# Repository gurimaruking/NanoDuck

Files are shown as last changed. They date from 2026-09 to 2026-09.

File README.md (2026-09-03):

# NanoDuck — MG90S で成立する小型二足アヒル

[MicroDuck](https://github.com/pollen-robotics/microduck)（250 mm / 800 g /
Dynamixel XL330 ×14 / 約 63,000 円のサーボ）を、**ホビーサーボで作り直した**もの。

MicroDuck を縮小コピーしたのではない。一度そう試して**幾何的に成立しないことを確認した**
（§3）ので、MG90S の形と能力に合わせて引き直してある。

数値はカタログ値の掛け算ではなく、**実機出荷版の歩行ポリシー `alpha_walking.onnx` を
CPU MuJoCo で 30 秒走らせて実測した関節トルク・角速度**
（`analysis/microduck_demand.npz`、5348 サンプル × 14 関節）から導いている。

```
analysis/  design_point.py      設計点の決定（質量 × 脚長 × サーボ割当）
           servo_sizing.py      初期検討（相似縮小の限界。経緯として残す）
cad/       build_nanoduck.py    MJCF を生成し、静的バランスを検証
           check_servo_fit.py   実装密度の検証 ← 部品を買う前にこれ
sim/       nanoduck.xml         生成されたモデル（10 DOF, 241 g、実メッシュ入り）
           stand_test.py        MG90S で立てるか
           run_mg90s.py         MicroDuck を MG90S で走らせる（アクチュエータ検証）
bom/       bom.csv              部品表
```

```bash
python cad/build_nanoduck.py   # モデル生成 + バランス検証
python sim/stand_test.py       # 立つか
```

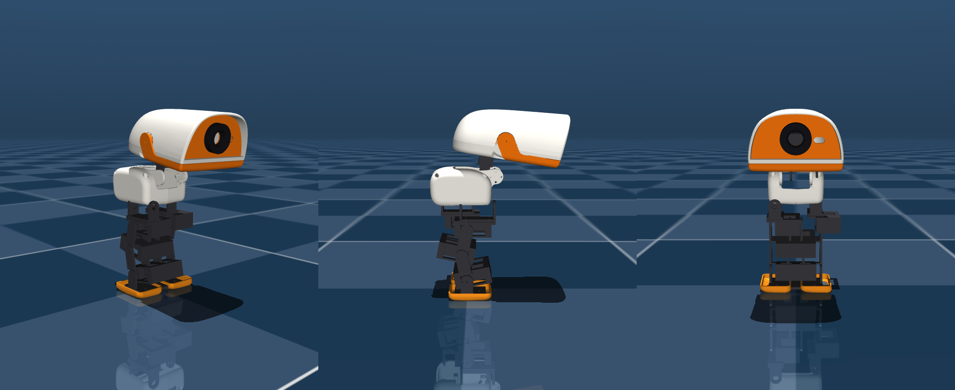
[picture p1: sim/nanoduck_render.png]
NanoDuck


上は箱ではなく**実物のジオメトリ**です。白いシェル(頭・胴・水かき足)は
MicroDuck 本体のメッシュを縮小したもの、黒い脚は `cad/print/` の印刷部品そのもの。
質量と慣性を担う箱はグループ3に隠してあり、`geomgroup` を切り替えれば質量モデルが見えます。

---

## 1. 設計点

| | MicroDuck | **NanoDuck v2** |
|---|---|---|
| 全高 | 250 mm | **177 mm** (71 %) |
| 質量 | 800 g (MJCF 737 g) | **284 g** (36 %) |
| 全長 × 全幅 | — | 130 × 83 mm |
| DOF | 14 | **10** |
| サーボ | XL330 ×14 @7.4 V | MG92B ×2（膝）+ MG90S ×7 + マイクロ ×1 @6.0 V |
| 制御 | RK3566 / Linux | ESP32-S3-MINI-1 |
| サーボ費用 | 約 63,000 円 | **約 7,300 円** (1/9) |
| 脚長（腿+脛） | 91.6 mm | 50 mm |
| 最悪関節の使用率 | 76 %（膝） | **90 %**（膝） |

質量と寸法は見積りではなく `sim/nanoduck.xml` の実測。**モデルが正**。

MicroDuck 自身が「限界設計だが成立している」76 % に座っているので、そこを上限に
設計した。いまは **90 %** で、上限を超えている。

**「見た目クリソツ」の代償が積み上がった結果**:

| 段階 | 質量 | 最悪関節 |
|---|---|---|
| 構造だけ（見積り） | 196 g | 62 % |
| 印刷部品の実測 + 外装 | 241 g | 76 % |
| **頭を本家比率（0.85）に** | **284 g** | **90 %** |

頭を本家と同じ head/body = 1.52 にすると +43 g かかる。0.62 のままなら比 1.11 で
27 % 小さく、「アヒルだが何か違う」という見え方になっていた（§8）。
90 % は `design_point.py` の転写が MicroDuck の**機敏な歩容**を前提にした上界なので、
再学習した歩容ならもっと軽い。ただし余裕が無いのは事実で、
**軽くしたいならまず頭のスケールを下げる**のが一番効く。

高さが 71 % にしか下がらないのは、**サーボと電池が縮まないから**（§2）。
一方で質量は 27 %、サーボ費用は 11 % まで落ちる。
「小さくする」より「軽くする・安くする」プロジェクトだと理解した方が正しい。

---

## 2. 設計変数は「相似縮尺 s」ではなく「質量」と「脚長」

最初は MicroDuck を s 倍する枠組みで考えたが、これは**間違った定式化**だった。
一つの s が全部に掛かるため、関節が実際に気にしている 2 つの量が独立に動かせない。

関節需要の転写則:

```
τ = τ_micro · (M/M_micro) · (L_leg/L_micro)     (τ ~ M·g·L)
ω = ω_micro · √(L_micro/L_leg)                  (振子周期 ~ √(L/g))
P ~ τ·ω ~ M · √L_leg
```

**質量は 1 乗、脚長は 1/2 乗でしか効かない。**
脚を半分にして得られるのは出力予算の 29 %、質量を半分にすれば 50 %。
だから設計努力は mm ではなく **g** に注ぐ。

MG90S の脚が運べる質量（最悪関節 ≤ 100 %）:

| 脚長 | 全部 MG90S | 膝だけ MG92B |
|---|---|---|
| **50 mm** | 220 g | **315 g** ← 採用 |
| 70 mm | 205 g | 245 g |
| 100 mm | 170 g | 180 g |

脚を 70 → 50 mm に詰めたのは、造形の都合が先だった（70 mm では竹馬に乗った
ロボットに見えて、アヒルに見えなかった）。結果としてトルク予算も 245 → 315 g に
増えて、**見た目の判断と工学の判断が同じ方を向いた**。
代償は歩幅と地上高で、屋内 177 mm のロボットなら払える。

**膝 2 個を格上げする方が、機体をどう削るより効く。**
+0.8 g・+1,100 円で予算が 40 g 増える。ここに金を使う。

### 質量には床(floor)がある

サーボ・電池・基板は縮まない。s³ で縮むのは構造材だけ。
NanoDuck では **196 g のうち構造材は 33 g（17 %）**しかなく、残りは全部固定質量。
「もっと小さくすれば軽くなる」は、この規模ではもう成り立たない。

> 初期の見積りでは電池と基板を s³ 項に入れていた。450 mAh の LiPo は縮まないので、
> これは小スケールを不当に有利に見せる誤りだった。CAD メッシュの実測
> （`np_f970.stl` は名前に反し **NP-F550 寸法と 0.2 mm 一致** = 約 76 g）で
> 3 項モデルに組み直してある。

---

## 3. 縮小コピーが成立しなかった理由 — MG90S は「小さい」のではなく「薄い」

| | 長さ | 高さ | 幅 | 質量 |
|---|---|---|---|---|
| XL330-M288 | 34.0 mm | 29.0 mm | 20.0 mm | 18.0 g |
| MG90S（耳込み） | 32.2 mm | 28.5 mm | 12.2 mm | 13.4 g |
| 比 | **0.95** | **0.98** | 0.61 | 0.74 |

よく言われる「MG90S は XL330 の 45 % の体積」は事実だが**完全にミスリード**。
連鎖方向の長さが制約なので、効くのは長さで、そこは **5 % しか縮んでいない**。

MicroDuck の股関節は 3 DOF を 71 mm に詰めている = サーボ 1 個あたり 23.7 mm、
XL330 は 34 mm なので**既に 43 % 重なっている**。0.56 倍にすると、
実証済みの実装密度の **1.7 倍**が要る。トルクではなく実装が律速だった。

### 解決 — サーボを横に倒す

MG90S の出力軸は 22.8×12.2 面から出る。ピッチ関節では軸が左右方向を向くので、
**32.2 と 12.2 を矢状面内で自由に選べる**。12.2 を脚に沿わせれば:

| | 連鎖長/サーボ |
|---|---|
| サーボを連鎖に沿わせる（MicroDuck 流） | 40.2 mm |
| **サーボを横に倒す** | **20.2 mm** |

NanoDuck は腿 25 mm / 脛 25 mm なので実装密度 **0.81**（MicroDuck は 1.44）。
ブロッカーは取付向きだけで消えた。代償は腿が前後に 32 mm 張り出すこと —
アヒルなら「もも肉」に見えるので、制約とキャラクタが珍しく一致している。

詳細: [cad/README.md](cad/README.md) / `python cad/check_servo_fit.py`

---

## 4. MG90S アクチュエータモデル — 実装済み・検証済み

`sim/mg90s.py`。`sim/run_mg90s.py` が microduck_rl の `infer_policy.py` を
そのまま駆動し、**アクチュエータだけ**を差し替える。

```bash
cd sim
python run_mg90s.py --servo xl330      # 対照群
python run_mg90s.py --servo mg90s-6v   # 本命
python run_mg90s.py --servo mg90s-6v --view
```

MuJoCo の `position` アクチュエータを**トルクモードに変換**し、毎物理ステップで計算:

```
err  = deadband(q_target − q)          # ポテンショは出力軸を読む
u    = clip(kp·err / τ_stall, −1, +1)  # アナログP制御 → PWMデューティ
τ    = τ_stall·u − (τ_stall/ω_noload)·q̇
```

第 2 項の逆起電力が**トルク-速度の三角形**を作る。`position` の平坦な `forcerange`
では「速く回すほどトルクが出ない」を表現できず、ベンチでは崩れるロボットが
シム内では平然と歩いてしまう。

### 対照群による較正（これが無いと信用できない）

最初の実装は「誤差 1° でフルドライブ」= 実効剛性 55 Nm/rad とし、MJCF の
`chosen_actuator` が定める **kp = 0.55 Nm/rad の 100 倍**だった。
結果、**XL330 の数値でも 2.4 秒で転倒**。対照群が歩かないならモデルが悪い。

副産物として良い整合が出た: MJCF の `damping = 0.053` は逆起電力項を持たない
position モデル用の値なので逆起電力を吸収しているはず。実際
0.053 − (0.963/20.2) = **0.0054** で、BAM が独立にフィットした
`friction_viscous = 0.00536` と **1 % 以内で一致**する。

### 結果（MicroDuck 実寸・出荷版歩行ポリシー・15 s）

| サーボ | 結果 |
|---|---|
| XL330 @7.4 V（対照群） | **歩く** 2.65 m / 14.3 s、飽和 0 % |
| MG90S @6.0 V | **1.1 s で転倒**、飽和 64 % |

### アブレーション — 犯人は「関節剛性ひとつ」

MG90S は XL330 と**出力**と**制御則**の 2 点で違う。片方ずつ入れ替えると
実寸では**どちらも単独で致命的**（出力だけ → 1.7 s、制御則だけ → 1.9 s で転倒）。

制御則をさらに 3 要素に分解:

| 変更（XL330 の出力のまま） | 結果 |
|---|---|
| 不感帯 1.0° | **歩く**（飽和 0 %） |
| 指令遅延 20 ms（50 Hz PWM 1 フレーム） | **歩く** |
| kp 0.8 / 1.0 / 1.2 Nm/rad | **歩く** |
| kp 1.5 Nm/rad | 5.1 s で転倒 |
| **kp 2.47 Nm/rad**（MG90S 相当） | **0.8 s で転倒** |

**ハード設計への含意:**
- **333 Hz PWM は不要** — 標準 50 Hz の 20 ms 遅延は問題にならない
- **不感帯 1° も許容** — 姿勢精度は落ちるが安定性は壊さない
- **効くのは関節剛性ひとつ** — MG90S は自身のトルクに対し XL330 の約 4.5 倍硬い

ただしこれは**未再学習のポリシー**の話。RL は硬いアクチュエータを扱えるので、
kp ≈ 2.5 をドメインランダム化に含めて学習し直せば解ける見込みが高い。
結論は「MG90S は無理」ではなく**「再学習は必須で、そのとき剛性が最重要パラメータ」**。

---

## 5. 立てるか — 立てる（が、それは簡単な方の問題）

`python sim/stand_test.py`。ポリシー無しで STAND 姿勢を保持させ、重力をかける。

| サーボ | 結果 |
|---|---|
| XL330（対照群） | 立つ。たわみ 0.2 mm、rms 0.00 mm、飽和 0 % |
| **設計どおり（MG92B 膝 + MG90S + マイクロ）** | **立つ。たわみ 0.2 mm、飽和 0 %** |
| 全部 MG90S | 立つ。同上 |

不感帯 1° があってもリミットサイクルは出ず、静止する。

**ただしこれは簡単な方の問題**で、静的保持では 3 構成に差が出ない。
横から押すと 0.15 m/s でも全構成が転ぶが、そのとき**サーボは一度も飽和していない** —
つまりトルク不足ではなく**バランス制御が無いから**倒れている。
固定姿勢の保持に外乱復帰はできない。それはポリシーの仕事で、
`stand_test.py` はこの 2 つの失敗モードを区別して報告する。

**設計を本当に検証するのは、10 DOF で再学習した歩行ポリシー**。
`analysis/design_point.py` が心配しているのは遊脚期の出力であって、静止時の保持ではない。

### 最初のモデルは後ろに倒れた

ホームポーズに MicroDuck の関節角（腿 −26.2°、膝 ≈0、足首 +26.2°）を
数値のまま流用したのが原因。あれは**脚全体が前傾した**姿勢で、MicroDuck では
3 サーボの股関節クラスタが足を前に送り出して釣り合う。
単純な 2 軸股関節に入れると足が CoM より 31 mm 前に出て、後ろ向きに座り込む。

2 リンク脚で足首を股関節の真下に置く条件は **knee = −2·hip_pitch**、
足裏を水平にするのは **ankle = −(hip_pitch + knee)**。
いまはこれを式で導出しており、`build_nanoduck.py` が生成のたびに
**CoM が支持多角形に入っているか**を検証する（現在: 前後余裕 +16.2 mm、左右 +33.0 mm）。

---

## 6. 位置フィードバックが要る

観測 49 次元の内訳:

```
base_ang_vel(3) + gravity(3) + joint_pos(10) + joint_vel(10) + last_action(10) = 36
                                                            + command(13)      = 49
```

**関節エンコーダ由来が観測 36 次元中 20 次元**。MG90S は PWM 位置指令のみで出力を返さないので、
内部 5 kΩ ポテンショのワイパーを引き出す（[bom/README.md](bom/README.md) §4 に
落とし穴 3 つ: 分圧必須・低抵抗厳禁・コンデンサ容量）。

---

## 7. 残っている作業

1. **MG90S / MG92B のベンチ実測** — `sim/mg90s.py` の `kp`・不感帯・ストールトルクは
   推定値。シムの結論は kp に最も敏感なので、ここが最優先。
   MG92B のカタログ値はベンダー間でばらつきが大きく、設計はこれに依存している
2. **再学習** — `Mjlab-Velocity-Flat-NanoDuck` を登録し、MG90S アクチュエータモデルと
   kp のドメインランダム化を入れて PPO。観測 49 / 行動 10 の新しい契約になる
3. **機構設計** — サーボ横倒しレイアウトで実際に CAD を引く。
   `sim/nanoduck.xml` は箱を並べた運動学モデルであって、製造できる形状ではない。
   Onshape の MicroDuck は公開されている（[cad/README.md](cad/README.md)）が、
   参照用であって派生元にはしない
4. **ESP32-S3 への載せ替え** — 49→128→128→10 なら 23k パラメータ = 92 KB で
   量子化なしに内蔵 SRAM に載る

---

## ライセンス

上流 microduck_rl と同じ 2 分割構成:

- **コード** (`analysis/`, `sim/*.py`, `cad/*.py`, ドキュメント) — [Apache 2.0](LICENSE)
- **3D モデル** (`cad/microduck_src/`) — **CC BY-NC-SA 4.0**。
  Pollen Robotics の [microduck_rl](https://github.com/pollen-robotics/microduck_rl)
  からのコピーで、**商用利用不可・継承必須**。派生物である
  `analysis/microduck_demand.npz` も同条件

詳細と、なぜこれらのファイルを同梱しているかは [NOTICE.md](NOTICE.md)。

本家は Pollen Robotics の [MicroDuck](https://pollen-robotics.com/microduck)。
NanoDuck は非公式の独立リデザインで、Pollen Robotics とは関係ありません。

---

## 8. 頭部まわりの監査（未解決を含む）

### 比率 — 直した

MicroDuck の head/body 比は **1.52**。頭 0.62 / 胴 0.85 と別スケールにしていたため
NanoDuck は **1.11** で、27 % 小さかった。これが「アヒルだが何か違う」の正体。
頭を胴と同じ 0.85 にして 1.52 を厳密に回復した（+43 g、膝 76 → 90 %）。

### head_yaw の駆動 — 足りていなかった

`design_point.py` は頭の関節需要も**脚長でスケール**していた。首サーボが支えるのは
脚ではなく頭なので、これは誤り。頭のスケールで転写し直すと:

| | 旧（脚スケール） | 新（頭スケール） |
|---|---|---|
| head_yaw 必要トルク | 0.038 Nm | **0.050 Nm** |
| マイクロ 3.7 g の使用率 | 83 % | **102 %（成立しない）** |

→ head_yaw を **MG90S に格上げ**（27 %）。neck_pitch はマイクロのままでよい（34 %）—
こちらは短いアームで重力に抗するだけで、頭の慣性を振り回さない。

### センサ — 穴はあるが中身が無い

| | MicroDuck | NanoDuck |
|---|---|---|
| サイト | imu, imu_bno, head_camera, mouth_tip, tof, head_imu | imu, head_camera, **tof**, **head_imu**, mouth_tip |
| 実カメラ | RPi カメラ + M12 レンズ | **無し（`ncam = 0`）** |
| ToF | 有り | **無し** |

サイトは MicroDuck と同じ名前で揃えた（歩行の観測は胴の IMU だけなので機能上は不要だが、
外装が MicroDuck 製で**穴が開いている**以上、位置はモデルに書いておくべき）。

**未解決**: 頭のシェルにはレンズ穴と ToF 窓があるのに、BOM には何も入っていない。
どちらかを選ぶ必要がある:
- **目隠しプラグを印刷する**（軽い。歩行には何も要らない）
- **OV2640 等を積む**（ESP32-S3 で駆動可。ただし §3 の「歩行だけ」という前提が変わる）

### 腰まわり — サーボは全部ある。フレームが無い

`cad/build_nanoduck.py` の `check_joints()` で確認済み:

- サーボ 10 個すべてモデルに存在（hip_roll ×2 と neck_pitch は胴に載っている）
- 軸の向き、ホームが範囲内、キーフレーム一致、ctrlrange 一致、左右の鏡像性、
  膝の符号（足首が股関節の真下 ±0.00 mm）— **全項目合格**

**未解決**: hip_roll サーボ 2 個を保持する**胴体シャーシがまだ描かれていない**。
質量 12 g で見積もってあるだけで、印刷部品が無い。
`cad/print/` に無い唯一の構造部品で、ここが腰まわりの本当の穴。

### 首まわり — 3 件とも実バグだった

「首まわりがおかしい」で見つかったもの:

1. **首の印刷部品が上下逆** — `parts.link()` は全部品を「駆動側が −Z」で作る。
   脚 6 部品はこれで正しいが、首だけは **+Z**（頭は上）。
   部品は z = −44〜+5 に伸びていて、**頭のある上ではなく胴の中へ向いていた**。
   親の部品が自分の駆動する関節位置に届いているかを検証する
   `check_joints()` の到達テストで検出（脚 6 部品は合格、首だけ不合格）。

2. **頭が胴に 10.6 mm めり込んでいた** — これが「首が見えない」の正体。
   首が無いのではなく、頭が胴の中にあった。`NECK_SINK = 8` と `HEAD_Z = 4` は
   37 mm の頭には妥当だったが、0.85 で 50 mm になった頭には過補正。
   いまは**閉形式で導出せず測って収束させている**（`solve_head_z()`）—
   閉形式は 2 回間違えた（neck_pitch の傾きで頭の底面が下がる分、
   クラスタの重心が最下点ではない分を、どちらも落としていた）。
   `check_head_clearance()` がコンパイル済みモデルから実測する。

3. **色が無かった** — シェルは別部品なので個別に着色できる。実物は
   オフホワイト + **オレンジのくちばしと眉帯** + 黒い目。
   単色クリームだと「白い汎用ロボット」に見えてしまう。

なお「頭が 40° 傾いて見える」は**目視の誤り**で、実測ピッチは **+8.6°**
（= `NECK_PITCH_0` そのまま）。見えていた傾きは MicroDuck 自身の楔形の頭蓋。

### 腰まわり — 軸が平行だった（`8d6f5fb` で修正済み）

hip_roll と hip_pitch は**直交**しなければならないが、平行になっていた。
いま股関節は 2 部品のコーナーリンク（`hip_yoke_a` + `hip_yoke_b`）で、
`check_joints()` が軸の向きを検証している。

**未解決のまま**: hip_roll サーボ 2 個を保持する胴体シャーシは依然として未描画。
`cad/print/` に無い唯一の構造部品。

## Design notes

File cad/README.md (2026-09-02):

# CAD

```
microduck_src/     MicroDuck の原寸メッシュ(上流のコピー、47 STL + MJCF)
nanoduck_s050/     0.50 倍に縮小したもの(scale_meshes.py の出力、参考用)
scale_meshes.py    一様スケール
check_servo_fit.py MG90S が入るかの検証  ← 先にこれを読む
```

## 出典とライセンス

`microduck_src/` は [pollen-robotics/microduck_rl](https://github.com/pollen-robotics/microduck_rl)
の `src/mjlab_microduck/robot/microduck/assets/` をそのままコピーしたもの。

> 3D model files are licensed under Creative Commons **BY-SA-NC**.
> (microduck_rl の LICENSE 記載)

したがって `nanoduck_s050/` などの派生物も **CC BY-SA-NC** を継承する。
**商用利用不可**、**継承(SA)必須**、**表示(BY)必須**。

CAD の本体は Onshape にあり公開されている:
https://cad.onshape.com/documents/804927696f06d877f3f1803e

本気で作るならこれを自分のドキュメントにコピーしてパラメトリックに変更し、
[onshape-to-robot](https://github.com/Rhoban/onshape-to-robot) で再エクスポートする。
`microduck_src/config_mjcf_walk.json` がそのエクスポート設定そのもの。

---

## 先に読むこと — MG90S は「入らない」

```bash
python check_servo_fit.py
```

**MG90S は小さいサーボではない。薄いサーボである。**

| | 長さ | 高さ | 幅 | 質量 |
|---|---|---|---|---|
| XL330-M288 | 34.0 mm | 29.0 mm | 20.0 mm | 18.0 g |
| MG90S(耳込み) | 32.2 mm | 28.5 mm | 12.2 mm | 13.4 g |
| 比 | **0.95** | **0.98** | 0.61 | 0.74 |

よく言われる「MG90S は XL330 の 45 % の体積」は事実だが**完全にミスリード**。
連鎖方向の長さが制約なので、効くのは体積ではなく長さで、そこは **5 % しか縮んでいない**。

### なぜ「リンク長 ≥ サーボ長」では判定できないか

MicroDuck の股関節は 3 DOF を 71 mm の連鎖に収めている = **サーボ1個あたり 23.7 mm**。
XL330 は 34 mm なので、既にサーボ同士が 43 % 重なっている。
多自由度クラスタでは「入るか」ではなく**実装密度**で見るしかない:

```
実装密度 = サーボ長 ÷ (連鎖長 ÷ サーボ数)
```

| クラスタ | 連鎖 | 数 | mm/個 | MicroDuck 実績 | NanoDuck s=0.56 で必要 |
|---|---|---|---|---|---|
| 股 (yaw+roll+pitch) | 71.0 mm | 3 | 23.7 | 1.44 | **2.43** |
| 頭 (pitch+yaw+roll) | 73.7 mm | 3 | 24.6 | 1.38 | **2.34** |
| 腿→膝 | 42.2 mm | 1 | 42.2 | 0.81 | 1.36 |
| 脛→足首 | 49.4 mm | 1 | 49.4 | 0.69 | 1.16 |

**s=0.56 では MicroDuck が実証済みの密度の 1.7 倍が要る。**
これは幾何の問題なので、再学習でもギヤでも動かない。

### 制約が交差している

```
幾何:   MicroDuck と同じ実装密度を守るなら s ≥ 0.95(237 mm)= ほぼ縮まない
トルク: MG90S @6.0V が成立するのは s ≤ 0.56(140 mm)
                            ↑ 重ならない
```

**ここが NanoDuck の本丸**。トルクではなく実装が律速。

### 抜け道(安い順)

1. **DOF を減らす** — 一番きつい頭部クラスタ(pitch+yaw+roll が 24.6 mm/個)は
   歩行に不要。`head_yaw` と `head_roll` を落として 14 → **12 DOF**。
   再学習はどのみち必須なので、14 アクション契約を守る理由はない
2. **サーボを混ぜる** — 首・頭は s=0.56 換算で 0.018–0.025 Nm しか要らない
   (膝は 0.12 Nm)。3.7 g マイクロサーボで十分で、場所が空く
3. **遠隔駆動** — 膝・足首のサーボを胴体に移してリンク機構で駆動する。
   200 mm 以下の二足では定石。脚の体積が丸ごと空く。代償はバックラッシだが、
   これは `add_backlash.py` で既にモデル化されている

v1 BOM は 1 + 2 を採用している([../bom/README.md](../bom/README.md))。
3 は股関節が 12 DOF でもまだ密なので、いずれ必要になる可能性が高い。

---

## scale_meshes.py

```bash
python scale_meshes.py --scale 0.50
```

バイナリ STL を一様スケールする。一様スケールでは面法線は不変(単位ベクトル)なので、
三角形あたり 9 個の頂点 float だけを触る。スケール比は検証済み(実測 0.500)。

**これは形状確認とシム用**であって完成した機械設計ではない。スケールしないものが3つある:

- **サーボ座**: 全部 XL330 (29×20×34) 用に彫られている。MG90S は出力軸が片側のみで
  耳が横に出る、まったく別のインタフェース。全部引き直し
- **肉厚**: 0.5 倍は 2 mm の壁を 1 mm にする。FDM で出しにくい上に荷重的に足りない。
  肉厚は「絶対値」で戻すもので、スケールするものではない
- **買う部品**: ベアリング・ネジ・電池は実寸のまま。M2 は M2 のまま、
  MicroDuck の 22×16×4 ベアリングは MR63/MR83 になるのであって
  11×8×2(存在しない)にはならない

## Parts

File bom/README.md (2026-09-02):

# NanoDuck v2 — BOM と電装の設計判断

**設計点: 10 DOF / 脚長 50 mm / 実装質量 196 g / 全高 162 mm**
最悪関節 **62 %**（MicroDuck 自身の膝は 76 %。それより余裕がある）

数値は `sim/nanoduck.xml` の実測。**モデルが質量の正**であって、見積りではない。

MicroDuck をスケールした設計ではない。MG90S の形に**合わせて**引き直したもの。
根拠は `analysis/design_point.py`、機構の判断は [../cad/README.md](../cad/README.md)。

---

## 1. なぜ 10 DOF か

| | MicroDuck | NanoDuck v2 |
|---|---|---|
| 脚 | hip_yaw, hip_roll, hip_pitch, knee, ankle ×2 = 10 | hip_roll, hip_pitch, knee, ankle ×2 = **8** |
| 首・頭 | neck_pitch, head_pitch, head_yaw, head_roll = 4 | neck_pitch, head_yaw = **2** |
| 合計 | 14 | **10** |

- **hip_yaw を落とす**: 4 DOF 脚は歩行の古典的最小構成。旋回は左右非対称な歩幅で作れる
- **head_pitch / head_roll を落とす**: 頭部 3 DOF クラスタはロボット上で最も密（連鎖 24.6 mm/個）で、
  歩行には何も寄与しない
- **首と頭ヨーは残す**: 頭が動かないアヒルは家具

再学習は必須（[../README.md](../README.md) §4）なので、14 アクションの観測契約を守る理由はない。

## 2. サーボ — 膝だけ格上げする

関節ごとの必要トルクは**桁で違う**。全部同じサーボにするのは設計ではなく手抜き:

| 関節 | サーボ | 必要トルク | 使用率 |
|---|---|---|---|
| knee ×2 | **MG92B** | 0.071 Nm | **62 %** ← 律速 |
| head_yaw | マイクロ 3.7 g | 0.027 Nm | 59 % |
| hip_pitch ×2 | MG90S | 0.044 Nm | 35 % |
| ankle ×2 | MG90S | 0.032 Nm | 18 % |
| neck_pitch | マイクロ 3.7 g | 0.011 Nm | 18 % |
| hip_roll ×2 | MG90S | 0.025 Nm | 13 % |

**膝 2 個を MG92B にすると、積める質量の上限が 220 g → 315 g に増える（脚長 50 mm）。**
フットプリントは MG90S と同一（22.8×12.2）、+0.4 g、追加費用 1,100 円。
機体を 40 g 削る努力より圧倒的に安い。**ここに金を使う。**

> MG92B のスペックはベンダー間で数値がばらつく。ここでは保守側（0.31 Nm @6V）を
> 採ったが、**ベンチ実測するまで信用しないこと**。MG90S も互換品の個体差が大きいので、
> 同一ロットでまとめ買いする。

## 3. 制御 — ESP32-S3-MINI-1、開発ボードではなくモジュール

MicroDuck の出荷ポリシー実測: 入力 61 → 出力 14、約 193k パラメータ、775 KB (float32)。
NanoDuck は 10 DOF なので観測 49 次元・行動 10 次元に縮み、さらに軽くなる:

```
base_ang_vel(3) + gravity(3) + joint_pos(10) + joint_vel(10) + last_action(10) = 36
                                                            + command(13)      = 49
```

| | 値 | 判定 |
|---|---|---|
| 演算量 | 193k MAC × 50 Hz = 9.7 MMAC/s | S3 には軽い |
| float32 の重み | 775 KB | 内蔵SRAM 512 KB に**入らない** |
| **int8 量子化後** | **193 KB** | **内蔵SRAM に載る** |
| PSRAM から float32 | 38.8 MB/s | 帯域が際どい |

**判断: PSRAM 無しの N8 モジュール + ESP-DL int8 量子化。**
どのみち再学習するので MLP を 61→128→128→14（26k パラメータ = 104 KB）に
縮めれば量子化すら不要になる（10 DOF なら 49→128→128→10 で 23k = 92 KB）。
PSRAM 付きを買う理由がない。

**開発ボードではなくモジュールを使う理由**: DevKitC は 8 g あり、その大半は
USB コネクタとピンヘッダ。196 g の機体で 8 g は膝の使用率 2 ポイントに相当する。

基板は 40×30 mm の 2 層 1 枚に ESP32-S3-MINI / PCA9685 / MCP3208×2 / 6V BEC /
IMU / 分圧抵抗 20 本を載せる。ブレイクアウト 5 枚をやめると約 15 g と配線の大半が消える。

> MicroDuck の RK3566 はカメラ・WebRTC・ToF・Linux を回している。
> ESP32-S3 は**歩行に必要な部分だけ**。映像が要るなら別の設計になる。

## 4. サーボ位置フィードバック（ポテンショ・タップ）

MG90S / MG92B に位置出力は無いが、観測 36 次元中 20 次元が関節角度・角速度なので必須。
内部 5 kΩ ポテンショのワイパーを引き出す。**落とし穴が 3 つある**:

1. **電圧** — ワイパーはサーボ電源（6 V）基準。ADC の 3.3 V を超えるので**必ず分圧**する
2. **負荷** — そのポテンショはサーボ自身の制御ループが使っている。低抵抗で分圧すると
   **サーボが目標位置をずらす**。100 kΩ / 100 kΩ 以上にすること
   （5 kΩ 源に 200 kΩ 負荷 → 誤差 2.5 %、許容範囲）
3. **帯域** — 100 k/100 k の出力インピーダンスは 50 kΩ。MCP3208 は 10 kΩ 以下想定なので
   **10 nF** を足す（時定数 0.5 ms、50 Hz 制御に間に合う）。
   1 µF を付けると 50 ms になって制御が破綻する

**ADC**: 10 ch を 50 Hz 以上で読む。ADS1115 は **860 SPS しか出ないので不可**。
MCP3208（12 bit / 8 ch / SPI / 100 kSPS）× 2 が素直。

## 5. 電源 — 電池容量は「稼働時間」ではなく「関節トルク」の判断

MG90S ストール電流は約 700 mA。8 個で最悪 5.6 A。
歩行中の平均は 150–200 mA/個 = **1.2–1.6 A**。

- **6 V BEC は 6 A 以上**。基板に載せるならスイッチング型で
- サーボ電源とロジック電源は**必ず分ける**。突入で ESP32 がリセットする
- サーボレールに 470 µF 低ESR を基板上で 2 本

| 電池 | 質量 | 稼働 | 最悪関節 |
|---|---|---|---|
| 2S 300 mAh | 17 g | 約 12 分 | 59 % |
| **2S 450 mAh** | **28 g** | **約 19 分** | **62 %** ← 採用 |
| 2S 850 mAh | 48 g | 約 35 分 | 69 % |

脚を 70 mm から 50 mm に詰めたことで予算に余裕ができ、電池はもう律速ではなくなった。
450 mAh は 19 分・使用率 62 % で、850 mAh に増やしても 69 % なのでまだ成立する。
重量が効く設計であることは変わらないので、まず 450 mAh で始める。

---

## BOM

[bom.csv](bom.csv)。購入合計 **約 28,700 円**（予備込み）。
うちサーボは約 7,300 円 — XL330 ×14 の約 63,000 円に対して **1/9**。

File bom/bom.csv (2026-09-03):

category | item | spec | qty | unit_price_jpy | subtotal_jpy | mass_g_each | on_robot_g | notes
servo | MG92B | metal gear / ~3.1kgf-cm @6V / 13.8g | 3 | 900 | 2700 | 13.8 | 27.6 | KNEES ONLY (2 + 1 spare). Same 22.8x12.2 footprint as MG90S, +0.4g, ~45% more torque. Moves the mass budget from 205g to 245g -- cheaper than any airframe diet. PROVISIONAL SPEC: bench-measure before trusting.
servo | MG90S | metal gear / 2.2kgf-cm @6V / 13.4g | 9 | 350 | 3150 | 13.4 | 93.8 | 7 used (hip roll x2, hip pitch x2, ankle x2, HEAD YAW) + 2 spare. head_yaw was a 3.7g micro until the head grew to MicroDuck proportions: 54g of shell at 0.85 scale puts a micro servo at 102% of its envelope. Buy one lot; clones vary.
servo | micro servo 3.7g | ~0.06Nm / 20x8.4x20mm | 2 | 600 | 1200 | 3.7 | 3.7 | 1 used (neck_pitch) + 1 spare. neck_pitch works against gravity on a short arm (34%); head_yaw works against the head's inertia and needed an MG90S.
compute | ESP32-S3-MINI-1-N8 | 8MB flash / no PSRAM | 2 | 900 | 1800 | 1.0 | 1.0 | Module, not a devkit: a devkit is 8g of USB connector and headers we do not need. No PSRAM because the policy is quantised to int8 (193KB) and lives in internal SRAM.
compute | custom control PCB | 40x30mm 2-layer | 1 | 3000 | 3000 | 11.0 | 11.0 | Carries the ESP32-S3-MINI, PCA9685, MCP3208, 6V BEC, IMU and the 10 pot dividers. One board instead of five breakouts saves ~15g and most of the wiring.
driver | PCA9685 | 16ch 12-bit PWM I2C (bare IC) | 2 | 300 | 600 | 0.2 | 0.2 | 10 servos; ESP32-S3 LEDC has only 8 channels.
sensing | MCP3208 | 12-bit 8ch SPI ADC 100kSPS | 2 | 400 | 800 | 0.3 | 0.3 | 10 pot-tap channels needs 2. ADS1115 at 860 SPS is far too slow -- do not substitute.
sensing | ICM-42688-P | 6-axis IMU SPI (bare IC) | 2 | 1500 | 3000 | 0.1 | 0.1 | Only gyro(3) + accel(3) are in the observation. MPU-6050 works for v1 if cost matters.
power | LiPo 2S 450mAh LiHV | 7.4V 30C ~28g | 2 | 1600 | 3200 | 28.0 | 28.0 | ~19 min walking at ~1.5A. 850mAh is +20g and costs 4 points of joint margin -- see README 5.
power | switching BEC 6V 6A |  | 1 | 1200 | 1200 | 10.0 | 0.0 | Only if not integrating the BEC on the PCB. 5A is NOT enough: 8 servos stalling is ~5.6A.
power | XT30 connector pair |  | 2 | 150 | 300 | 2.0 | 2.0
power | electrolytic 470uF 16V | low ESR | 2 | 60 | 120 | 1.5 | 3.0 | Across the servo rail, at the board.
sensing | resistor 100k 1% | 0603 | 30 | 3 | 90 | 0.01 | 0.3 | Pot dividers, 2 per channel. NOT lower: loading the 5k pot shifts the servo.
sensing | capacitor 10nF | 0603 | 15 | 3 | 45 | 0.01 | 0.15 | ADC anti-alias. NOT 1uF: 50ms time constant would break 50Hz control.
wiring | silicone wire 26AWG | servo power | 2 | 400 | 800 |  | 5.0
wiring | ribbon + JST-SH assortment | signal | 1 | 800 | 800 |  | 3.0
mech | bearing MR63ZZ | 3x6x2.5mm | 12 | 120 | 1440 | 0.4 | 4.0 | MG90S output shaft is single-sided; every joint needs an idler bearing opposite the horn.
mech | carbon rod 3mm | for the shin | 1 | 500 | 500 |  | 2.0
mech | M2 screw assortment | 6/8/10mm + nuts | 1 | 1200 | 1200 |  | 6.0
mech | PETG filament | 1kg | 1 | 2500 | 2500 |  | 33.0 | ~33g printed: trunk shell 10, 8 joint brackets 12, feet 7, head/neck 4. Building the geometry turned up brackets the first round-number estimate missed. PETG over PLA: the joints see real load.
 |  |  |  | PURCHASE TOTAL | 29445 |  |  | Includes spares. Servo cost ~7050 JPY vs ~63000 for 14 XL330.
 |  |  |  | ON-ROBOT MASS |  |  | 283.7 | Matches sim/nanoduck.xml exactly -- the model is the authority on mass. Worst joint: knee at 90%. It was 62% before the shells and 76% before the head was brought to MicroDuck proportions; looking right costs 87g and 28 points of margin.

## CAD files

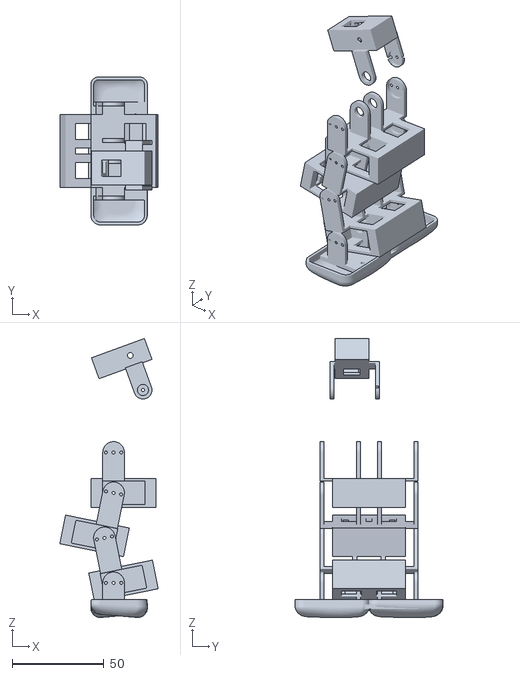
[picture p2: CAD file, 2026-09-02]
cad/print/assembly.stl
53.6 x 80.5 x 151.9

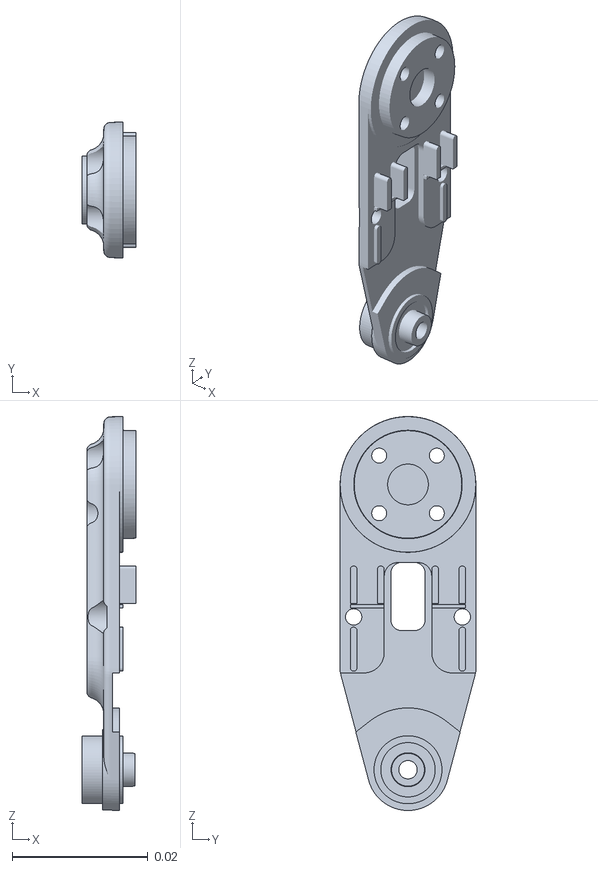
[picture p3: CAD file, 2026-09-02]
cad/microduck_src/leg.stl
0.00795 x 0.02 x 0.058

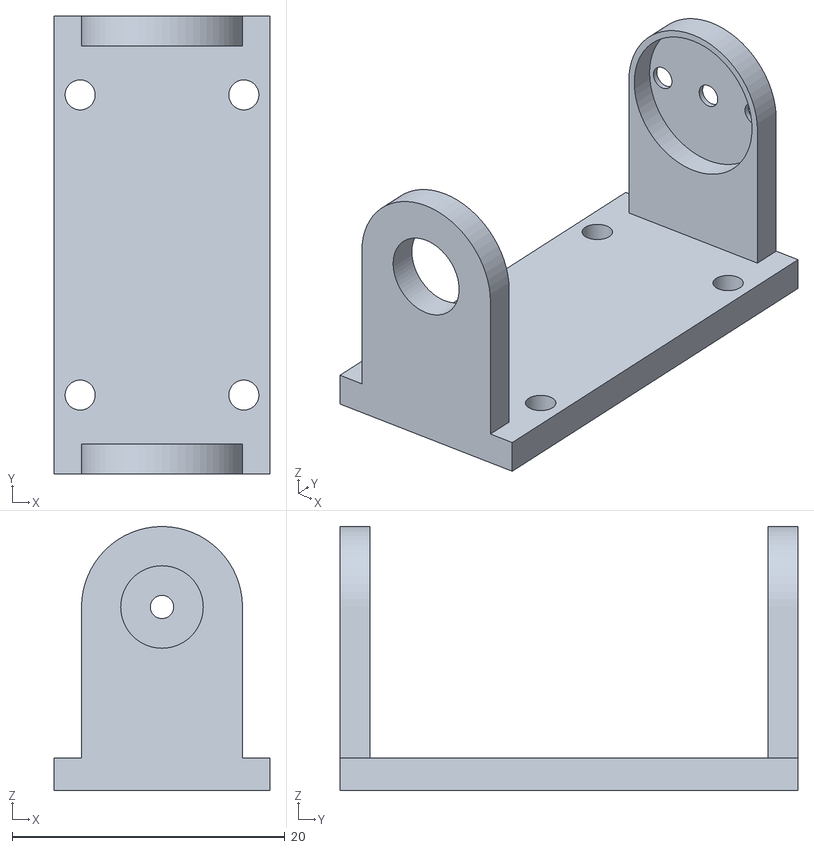
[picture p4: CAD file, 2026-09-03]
cad/print/hip_yoke_a_L.stl
15.8 x 33.6 x 19.3

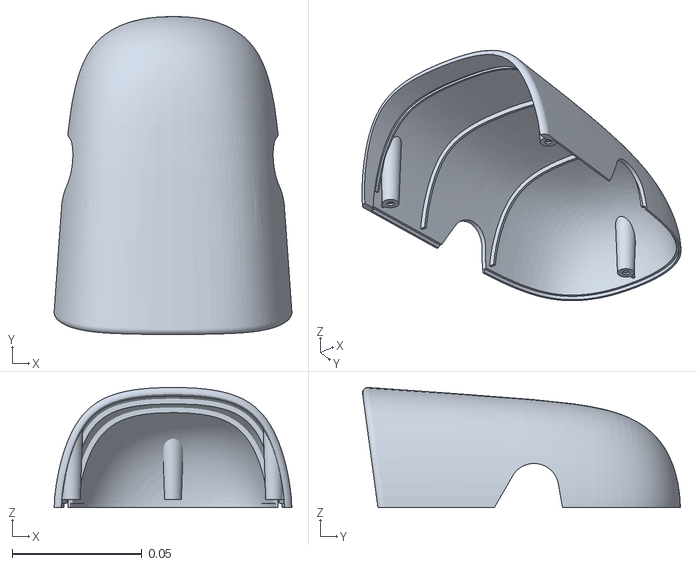
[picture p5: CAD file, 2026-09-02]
cad/microduck_src/top_head_shell.stl
0.0918 x 0.123 x 0.0463

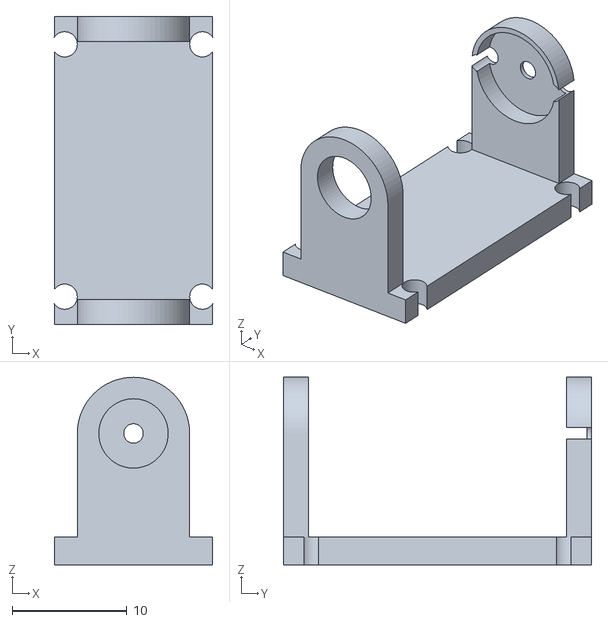
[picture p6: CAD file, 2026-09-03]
cad/print/neck_link_a.stl
13.8 x 26.8 x 16.3

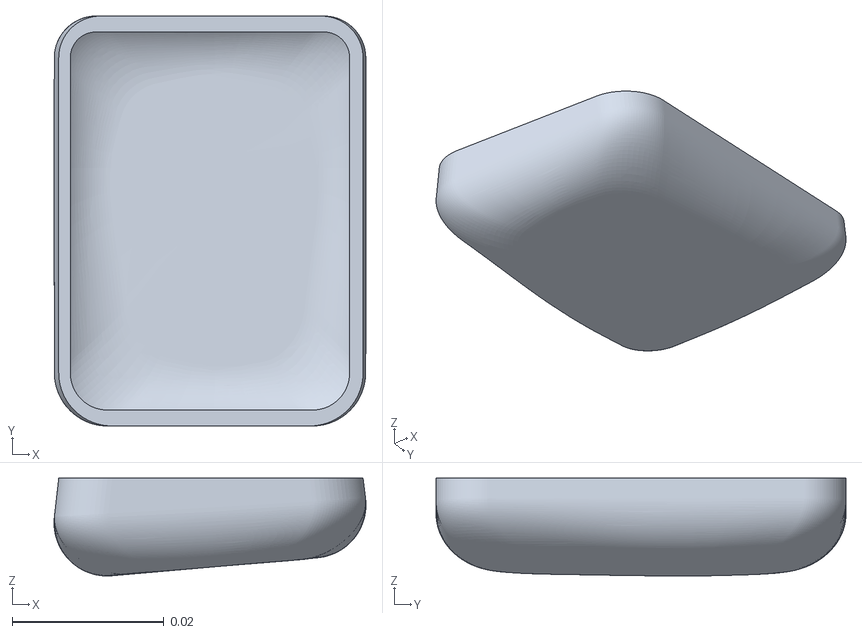
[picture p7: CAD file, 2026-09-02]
cad/microduck_src/sole_left.stl
0.0411 x 0.054 x 0.0129

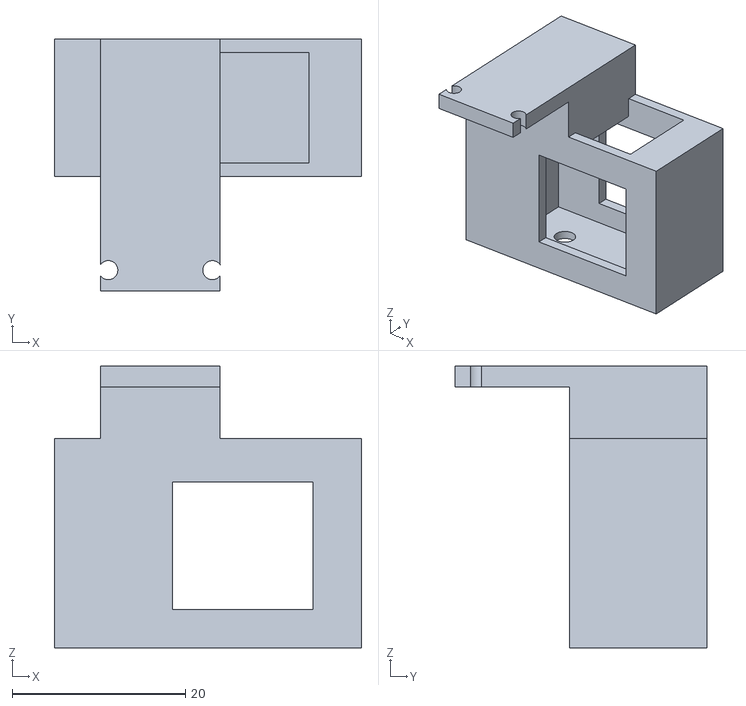
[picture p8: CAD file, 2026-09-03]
cad/print/neck_link_b.stl
35.4 x 29.1 x 32.5

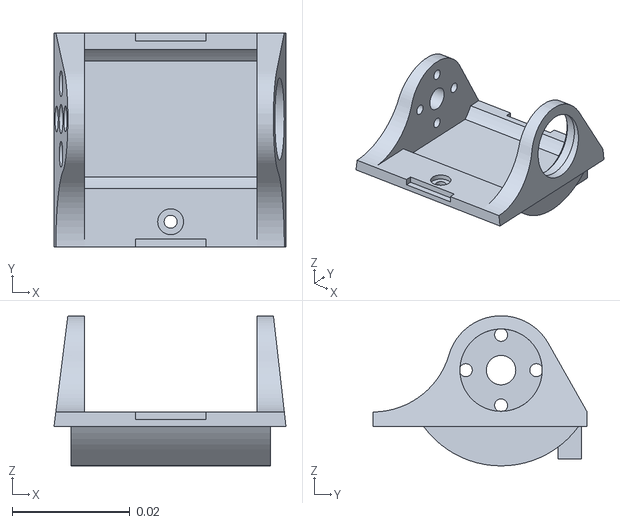
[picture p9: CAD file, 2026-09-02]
cad/microduck_src/ankle_right.stl
0.0395 x 0.0365 x 0.0255

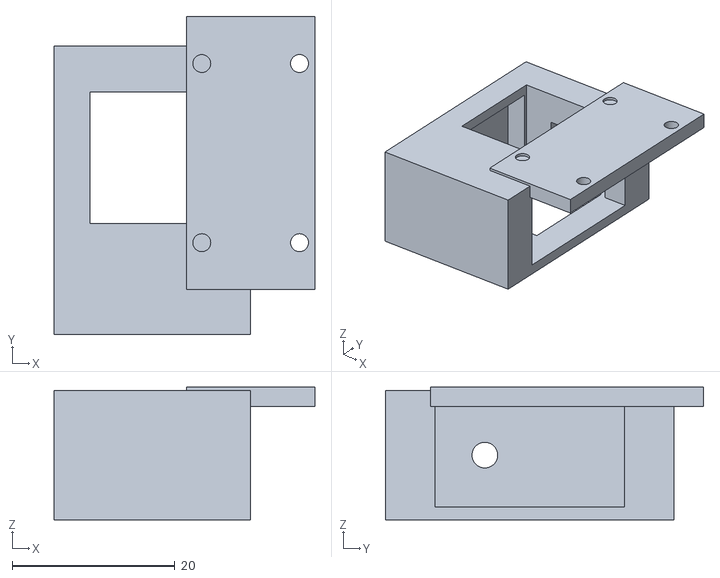
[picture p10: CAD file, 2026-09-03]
cad/print/hip_yoke_b_R.stl
32.0 x 39.1 x 16.3

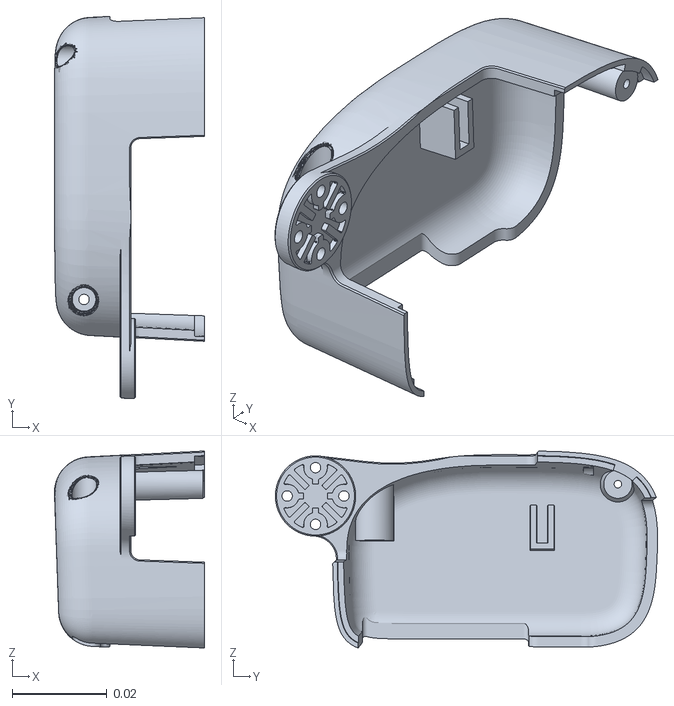
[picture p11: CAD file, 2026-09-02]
cad/microduck_src/right_shell.stl
0.0318 x 0.0809 x 0.0417

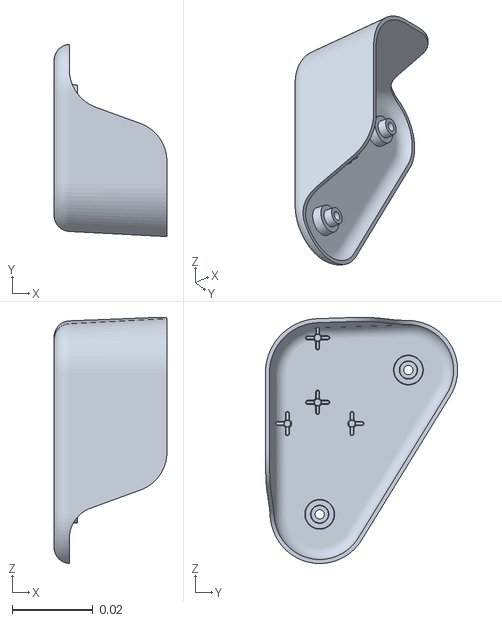
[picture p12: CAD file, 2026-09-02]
cad/microduck_src/right_upper_leg.stl
0.028 x 0.0477 x 0.061

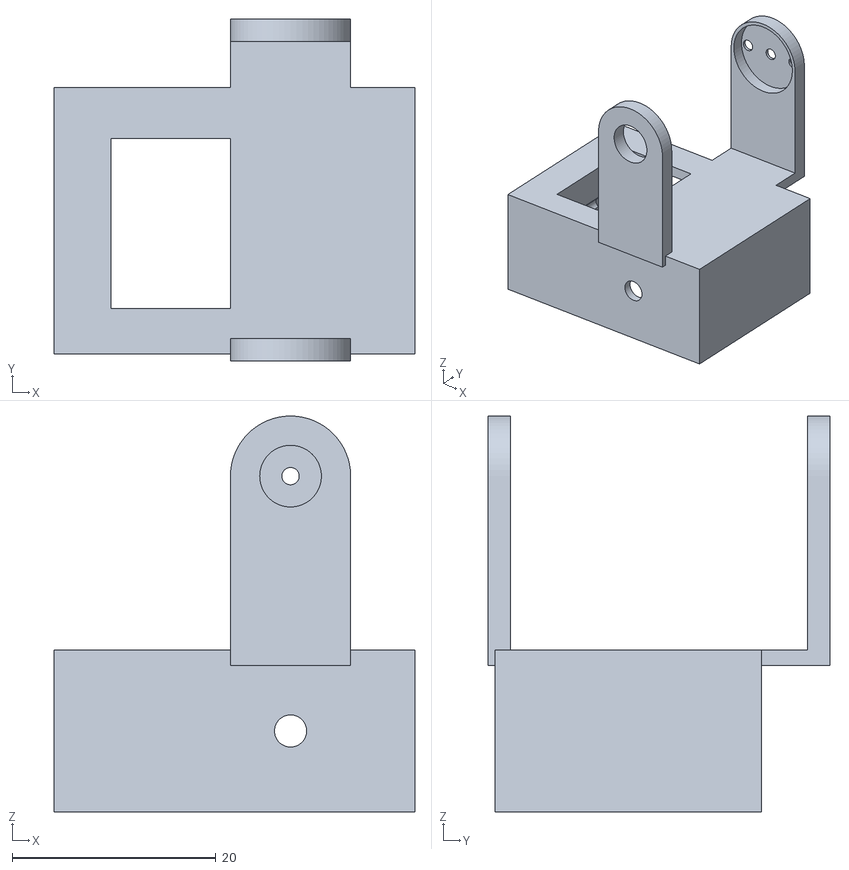
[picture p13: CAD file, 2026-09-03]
cad/print/thigh_L.stl
35.4 x 33.6 x 38.9

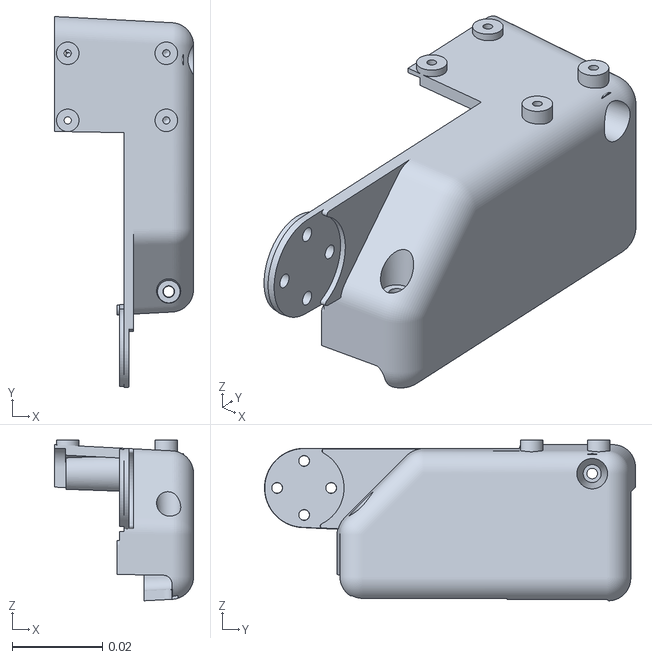
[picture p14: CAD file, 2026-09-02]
cad/microduck_src/trunk_shell_left.stl
0.0309 x 0.0824 x 0.0357

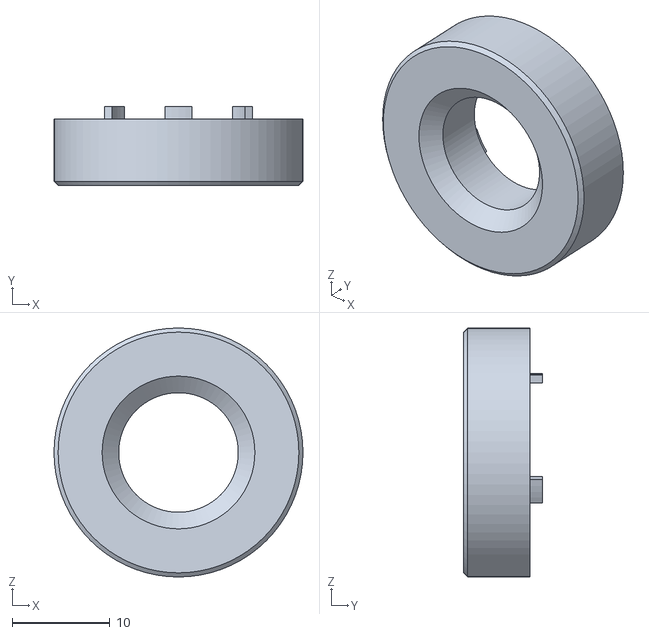
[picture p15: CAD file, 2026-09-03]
cad/print/cosmetic_noenoeil.stl
25.5 x 8.08 x 25.5

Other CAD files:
cad/print/hip_yoke_a_R.stl
cad/microduck_src/sole_right.stl
cad/print/hip_yoke_b_L.stl
cad/microduck_src/neck.stl
cad/microduck_src/ankle_l_v1.stl
cad/microduck_src/ankle_left.stl
cad/microduck_src/ankle_r_v1.stl
cad/microduck_src/banana_pcb_locker.stl
cad/microduck_src/bearing_roll.stl
cad/microduck_src/bottom_head_shell.stl
cad/microduck_src/elec_rpi_robot_hat_pcb.stl
cad/microduck_src/face_part.stl
cad/microduck_src/foot_left.stl
cad/microduck_src/foot_right.stl
cad/microduck_src/hip_l.stl
cad/microduck_src/jaw.stl
cad/microduck_src/jaw_soft.stl
cad/microduck_src/left_shell.stl
cad/microduck_src/left_upper_leg.stl
cad/microduck_src/lens.stl
cad/microduck_src/m12_lens_holder.stl
cad/microduck_src/motor_support.stl
cad/microduck_src/neck_pitch.stl
cad/microduck_src/noenoeil.stl
cad/microduck_src/np_f970.stl
cad/microduck_src/pcb__raspberry_pi_zero_2_w.stl
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

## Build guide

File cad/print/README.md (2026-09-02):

# NanoDuck 印刷部品

`python ../parts.py` で生成。20 STL、印刷質量 **64 g**(予備・治具を除く)。

> **最初に `fit_coupon_carrier` と `fit_coupon_yoke` だけ印刷してください。**
> 10 分で刷れて、サーボ・ベアリング・M2 ネジの嵌合を全部確認できます。
> ここで合わなければ、それは `../servo_spec.py` の数値が手持ちのサーボと違うという意味で、
> **16 個の構造部品すべてが同じように間違っています。**

---

## 1. 部品表

### 構造(パラメトリック生成)

| 部品 | 個数 | 印刷質量 | 外形 | 中身 |
|---|---|---|---|---|
| `hip_yoke_L/R` | 2 | 2.89 g | 35×34×36 | hip_roll に跨り、hip_pitch サーボを保持 |
| `thigh_L/R` | 2 | 3.14 g | 35×34×39 | hip_pitch に跨り、膝サーボ(MG92B)を保持 |
| `shin_L/R` | 2 | 2.97 g | 35×36×39 | 膝に跨り、足首サーボを保持 |
| `foot_mount_L/R` | 2 | 1.37 g | 30×34×20 | 足首に跨り、足裏を留める |
| `neck_link` | 1 | 1.67 g | 31×27×31 | neck_pitch に跨り、head_yaw サーボを保持 |
| `fit_coupon_carrier` | 治具 | 3.96 g | 44×27×26 | 嵌合テスト |
| `fit_coupon_yoke` | 治具 | 0.86 g | 12×34×23 | 嵌合テスト |

### 外装(MicroDuck 実物メッシュの縮小)

| 部品 | 縮尺 | 印刷質量 | 外形 |
|---|---|---|---|
| `cosmetic_top_head_shell` | 0.62 | 8.14 g | 57×76×29 |
| `cosmetic_bottom_head_shell` | 0.62 | 6.48 g | 57×72×12 |
| `cosmetic_jaw` | 0.62 | 2.55 g | 57×43×18 |
| `cosmetic_face_part` | 0.62 | 1.59 g | 54×8×28 |
| `cosmetic_noenoeil`(目、2個) | 0.62 | 1.16 g | 19×6×19 |
| `cosmetic_left_shell` / `right_shell` | 0.85 | 7.99 / 7.87 g | 29×69×35 |
| `cosmetic_sole_left` / `right` | 0.75 | 3.01 g | 31×40×10 |

外装は**模倣ではなく本物**です。Pollen Robotics の
[microduck_rl](https://github.com/pollen-robotics/microduck_rl) のメッシュそのもの
(**CC BY-NC-SA**、[../../NOTICE.md](../../NOTICE.md))。頭と胴で縮尺が違うのは、
胴が縮まない電池と基板を飲み込む必要があるためです。

> **クリソツの代償**: 外装だけで 43 g あり、膝の使用率を 62 % → **76 %** に押し上げます。
> 62 % は MicroDuck より余裕がある状態、76 % は MicroDuck と同じ限界設計です。
> 見た目を取るか余裕を取るかは、この 43 g の判断です。

---

## 2. 印刷設定

| | |
|---|---|
| 材料 | **PETG**(PLA 不可 — 関節に実荷重がかかる) |
| ノズル / 層厚 | 0.4 mm / 0.2 mm |
| 外周 | **4**(壁 1.6 mm を前提に設計) |
| 上下面 | 4 層 |
| インフィル | 35 % gyroid |
| サポート | **不要**(サーボポケットは +Y に開口、全オーバーハングが造形面を向く) |
| 配置 | 構造部品は**キャリア底面を造形板に**。層が関節荷重と直交します |

PLA で刷る場合は `../servo_spec.py` の `CLEAR` を 0.25 → 0.15 に下げてください
(PETG の膨張を見込んだ値です)。

---

## 3. 組立

必要なハード(1 関節あたり):

- M2 タッピングねじ ×2(サーボの耳)
- M2 タッピングねじ ×3(ホーンをヨーク腕へ)
- MR63ZZ ベアリング ×1(3×6×2.5)
- 3 mm ピンまたは M3 ねじ、長さ 8 mm ×1

手順(1 関節):

1. サーボをキャリアに **+Y 側から落とし込む**。耳が座に密着すること
2. 耳を M2 タッピング ×2 で締める。締めすぎるとボスが割れます
3. MR63ZZ をヨークの **−Y 腕**に圧入
4. ホーンをヨークの **+Y 腕**の座に落とし、M2 タッピング ×3 で固定
5. ホーンをサーボのスプラインに嵌め、付属の中心ねじで留める
6. 3 mm ピンをキャリア底面の穴からベアリング内輪へ通す

**必ずサーボを中立位置に合わせてからホーンを嵌めてください。** ホーンは 18° 刻みでしか
噛まないので、ずれると可動域の非対称(下記)が逆側に出ます。

---

## 4. 可動域は「実測値」です

`parts.py --check` が各関節を掃引し、子のヨークが親のキャリアに当たる角度を
ブーリアン交差で測っています。レンダリングでは絶対に見えません。

| 関節 | 可動域 | ホーム位置 |
|---|---|---|
| hip_pitch | **−32.5° 〜 +100.0°** | +11.5° |
| knee | **−102.5° 〜 +32.5°** | −22.9° |
| ankle | **−10.0° 〜 +22.5°** | +11.5° |

非対称なのはサーボ本体が前後の片側に張り出しているためです。
**膝キャリアだけ X 反転**してあり、広い 100° 側が実際に膝が曲がる向きに来ています
(反転前はホーム −22.9° に対し限界 −25°、余裕 2° しかありませんでした)。

これらは `../build_nanoduck.py` の `JOINTS` にそのまま入っていて、
MJCF の関節リミットになります。**機構が回らない角度を学習させないため**です。

> ⚠️ **足首の 32° が現状いちばん厳しい制約**です。歩容を縛るはずなので、
> 機構側で次に直すならここです。

---

## 5. まだ無いもの

- **胴体シャーシ** — hip_roll サーボ ×2、首サーボ、電池、基板を保持する枠。
  質量 12 g で見積もってありますが、まだ描いていません
- **外装の位置合わせ** — `preview.py` は構造部品しか配置しません。
  MicroDuck のシェルは Onshape 由来の原点と軸を持っており、
  当てずっぽうで置いたら「それらしく見えて間違っている」結果になったので外しました
- **MG92B の実測** — カタログ値がベンダー間でばらつきます。設計はこの数値に乗っています

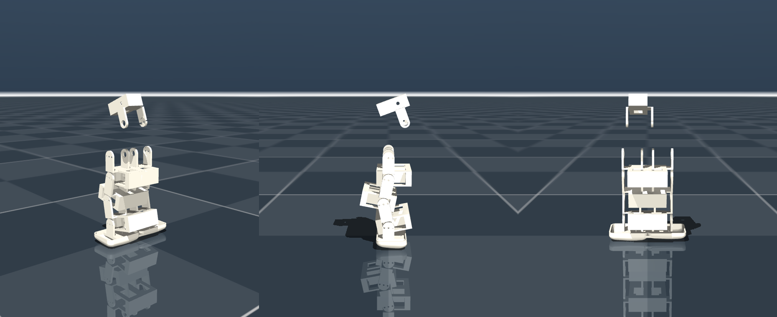
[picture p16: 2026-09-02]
cad/print/assembly.png

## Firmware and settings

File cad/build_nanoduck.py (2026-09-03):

#!/usr/bin/env python3
"""Generate the NanoDuck MJCF from the design parameters.

    python build_nanoduck.py

Writes `sim/nanoduck.xml` (the robot) and `sim/scene_nanoduck.xml` (floor,
lighting, keyframes).

Why generated rather than hand-written
--------------------------------------
Every number in this file traces back to a decision recorded elsewhere in the
repo -- servo masses to bom/bom.csv, leg length and total mass to
analysis/design_point.py, the servo orientation to cad/check_servo_fit.py.
Generating the XML keeps those links live: change LEG or a servo mass here and
the model, the keyframe and the actuator limits all move together.

MicroDuck's own MJCF is an Onshape export full of quaternions like
`0.5 -0.5 0.5 -0.5`, because the CAD frames are whatever SolidWorks made them.
This one is built the other way round: every body frame is axis-aligned with
the world in the home pose, so joint axes are literally "1 0 0" / "0 1 0" /
"0 0 1" and the model can be read.

Layout
------
10 DOF, in the left-leg / head / right-leg order MicroDuck uses, so the
observation and action vectors keep the same shape of layout:

    0-3   left  hip_roll, hip_pitch, knee, ankle
    4-5   neck_pitch, head_yaw
    6-9   right hip_roll, hip_pitch, knee, ankle

Servos are mounted TRANSVERSE: the 12.2 mm thin axis runs along the leg and the
32.2 mm long axis sticks out fore-aft.  That is what makes a 35 mm thigh
possible at all (cad/check_servo_fit.py), and it is why the thighs are visibly
chunky front-to-back.  On a duck that reads as drumsticks.

Each servo's mass sits on the link that CARRIES it, at the joint it DRIVES --
so the knee servo is part of the thigh, sitting at the knee end.  That places
mass distally, which is pessimistic and correct: it is where the real one goes.
"""

from __future__ import annotations

import os

import cosmetics as COS

HERE = os.path.dirname(os.path.abspath(__file__))
OUT = os.path.abspath(os.path.join(HERE, "..", "sim"))

MM = 0.001

# --- Servos (bom/bom.csv) -----------------------------------------------------
# box is (fore-aft, along-joint-axis, along-link) for the transverse mounting.
SERVO = {
    "MG90S": dict(mass=0.0134, box=(32.2, 28.5, 12.2), tau=0.216, kp=2.48),
    "MG92B": dict(mass=0.0138, box=(32.2, 30.5, 12.2), tau=0.310, kp=3.55),
    "micro": dict(mass=0.0037, box=(20.0, 20.0, 8.4), tau=0.060, kp=0.69),
}

# --- Geometry [mm] ------------------------------------------------------------
# Trunk, head and sole boxes are sized to the COSMETIC clusters they stand in
# for (cad/cosmetics.py prints the measured extents).  They carry the shells'
# mass, so if the box and the shell disagree the inertia is wrong -- the head
# was a 34x26x24 box standing in for a 76x57x37 shell until this was fixed.
TRUNK = (68.8, 54.4, 35.5)      # = cosmetic left_shell + right_shell at 0.85
HIP_Y = 20.0                    # half stance width at the hip
HIP_ROLL_TO_PITCH = 22.0        # roll and pitch axes are near-coincident
# LEG = 50 mm, down from a first cut at 70 mm.  Shorter legs are better on every
# axis that matters here: the mass budget rises from 245 g to 315 g
# (analysis/design_point.py), the CoM drops, and the proportions stop looking
# like a robot on stilts and start looking like a duck.  The cost is stride
# length and ground clearance, which a 170 mm robot indoors can afford.
# 25 mm still clears the 20.2 mm a transverse servo needs (cad/check_servo_fit.py).
THIGH = 25.0                    # hip_pitch -> knee
SHIN = 25.0                     # knee -> ankle
ANKLE_TO_SOLE = 12.0
FOOT = (40.5, 30.8, 4.0)        # footprint of the cosmetic sole at 0.75; kept
                                # thin as a contact box, the shell is visual
FOOT_X = 3.0                    # sole offset ahead of the ankle; centres the
                                # support polygon on the CoM (see check_static_balance)
NECK_X, NECK_Z = 16.0, 14.0     # neck_pitch axis, well forward on the trunk lid
NECK_LEN = 20.0                 # neck_pitch -> head_yaw (printed part length)
NECK_SINK = 8.0                 # how far the neck root sits INSIDE the trunk, so
                                # the head nestles instead of floating above it
HEAD = (104.3, 78.0, 50.4)      # = cosmetic head cluster at 0.85

# Where the head sits is DERIVED, not typed. Two hand-tuned numbers (NECK_SINK
# 8 mm and HEAD_Z 4 mm) were fine for a 37 mm head and buried a 50 mm one
# 10.6 mm inside the body -- which is what "the neck looks wrong" actually was:
# no neck was visible because the head was inside the trunk.
#
# Constraint: the underside of the head clears the top of the trunk by HEAD_GAP.
# Solving it here means changing the head scale cannot reintroduce the bug, and
# check_head_clearance() measures the result off the compiled model.
HEAD_GAP = 1.5                  # mm of daylight between head and body
HEAD_X = 18.0                   # head centre ahead of the head_yaw axis: the neck
                                # meets the skull toward its rear, as on MicroDuck,
                                # so the bill projects and the head does not sit
                                # over the tail
HEAD_Z = (TRUNK[2] / 2 + HEAD_GAP) - (TRUNK[2] / 2 - NECK_SINK) - NECK_LEN + HEAD[2] / 2


# --- Masses [kg] not accounted for by a servo box -----------------------------
# These are no longer estimates.  cad/parts.py generates the real printed parts
# and reports their volume; these are those volumes at PETG density and 35%
# infill (cosmetic shells are thin-walled CAD and print near solid, so they are
# counted at 90%).  Run `python parts.py --check` to regenerate the numbers.
#
# The round-number guesses this replaced were badly optimistic: 33 g of
# structure became 65 g once the geometry existed, mostly because MicroDuck's
# shells are bigger relative to a 162 mm robot than they look.
M_BATTERY = 0.028
M_PCB = 0.012
M_WIRING = 0.008
M_CHASSIS = 0.012               # trunk frame -- still an estimate, not yet drawn
M_TRUNK_SHELL = 0.0159          # cosmetic left_shell + right_shell at 0.85
M_HIP_YOKE = 0.00289
M_THIGH = 0.00314
M_SHIN = 0.00297
M_FOOT_MOUNT = 0.00137
M_SOLE = 0.00301                # cosmetic sole at 0.75
M_HEAD = 0.0543                 # top + bottom shell + face + jaw + 2 eyes at 0.85
                                # (mass goes as scale^3: 0.62 -> 0.85 is x2.6)
M_NECK_LINK = 0.00167

# --- Home pose [rad] ----------------------------------------------------------
# A symmetric crouch, derived rather than copied.  For a two-link leg with equal
# segments, the ankle sits directly under the hip when
#
#     THIGH*sin(hp) + SHIN*sin(hp + knee) = 0   ->   knee = -2*hp
#
# and the sole is horizontal when the joint angles sum to zero, i.e.
#
#     ankle = -(hp + knee) = hp
#
# The first attempt at this file copied MicroDuck's home pose numerically
# (hip -26.2 deg, knee ~0, ankle +26.2 deg).  That is a *leaning* leg, and it
# only balances on MicroDuck because its three-servo hip cluster carries the
# foot forward to meet it.  Dropped into a plain two-axis hip it puts the feet
# 31 mm ahead of the centre of mass, and the robot sits down backwards -- which
# is exactly what the first stand test did.
#
# The crouch is kept shallow (11.5 deg).  Knee torque in stance is mass times
# the horizontal offset from the knee axis, so a straight leg is cheapest; but
# a perfectly straight knee is a singularity it cannot push out of.  20 deg of
# knee bend costs ~7 mm of offset, about 13 mNm -- affordable, and it leaves the
# joint somewhere useful.
# Zero, not MicroDuck's 5 deg. There is no ankle ROLL joint on this leg, so any
# hip roll offset stands the robot on the outside edges of its soles. MicroDuck
# gets away with it on a compliant PU sole; a printed one would just rock.
HIP_ROLL_0 = 0.0
HIP_PITCH_0 = 0.20              # 11.5 deg
KNEE_0 = -2.0 * HIP_PITCH_0     # -22.9 deg, keeps the ankle under the hip
ANKLE_0 = HIP_PITCH_0           # levels the sole
NECK_PITCH_0 = 0.15             # a little forward lean; the head is heavy and
                                # the whole of it hangs off this one micro servo

# Leg pitch limits are MEASURED, not chosen: cad/parts.py sweeps each printed
# joint and finds where the child's yoke fouls the parent's carrier
# (`python parts.py --check`). They are asymmetric because the servo case
# sticks out one way -- the drumstick -- and the knee's carrier is mirrored so
# its wide side faces the direction the knee actually bends.
#
# The ankle is the tight one at 32 deg of total travel, and it is the clearest
# thing to fix next in the mechanics.
HIP_PITCH_RANGE = (-0.567, 1.745)     # -32.5 .. +100.0 deg
KNEE_RANGE = (-1.789, 0.567)          # -102.5 .. +32.5 deg
ANKLE_RANGE = (-0.175, 0.393)         # -10.0 .. +22.5 deg

JOINTS = [
    # name,             servo,   range (rad),      home
    ("left_hip_roll",   "MG90S", (-0.384, 0.384), -HIP_ROLL_0),
    ("left_hip_pitch",  "MG90S", HIP_PITCH_RANGE, HIP_PITCH_0),
    ("left_knee",       "MG92B", KNEE_RANGE,      KNEE_0),
    ("left_ankle",      "MG90S", ANKLE_RANGE,     ANKLE_0),
    ("neck_pitch",      "micro", (-1.571, 1.047), NECK_PITCH_0),
    ("head_yaw",        "micro", (-2.967, 2.967), 0.0),
    ("right_hip_roll",  "MG90S", (-0.384, 0.384), HIP_ROLL_0),
    ("right_hip_pitch", "MG90S", HIP_PITCH_RANGE, HIP_PITCH_0),
    ("right_knee",      "MG92B", KNEE_RANGE,      KNEE_0),
    ("right_ankle",     "MG90S", ANKLE_RANGE,     ANKLE_0),
]


def m(*v):
    """mm -> m, formatted for XML."""
    return " ".join("%.5f" % (x * MM) for x in v)


def half(box):
    return m(*(x / 2.0 for x in box))


def servo_geom(name, kind, pos_mm, group=3):
    s = SERVO[kind]
    return ('        <geom name="%s" type="box" size="%s" pos="%s" mass="%.5f" '
            'class="viz" rgba="0.15 0.15 0.17 1"/>\n'
            % (name, half(s["box"]), m(*pos_mm), s["mass"]))


def link_geom(name, size_mm, pos_mm, mass, rgba="0.85 0.72 0.25 1"):
    return ('        <geom name="%s" type="box" size="%s" pos="%s" mass="%.5f" '
            'class="viz" rgba="%s"/>\n'
            % (name, half(size_mm), m(*pos_mm), mass, rgba))


def leg(side, sign):
    """One leg subtree. `sign` is +1 for left (+Y), -1 for right."""
    roll0 = -HIP_ROLL_0 if side == "left" else HIP_ROLL_0
    x = []
    a = x.append
    # One source of truth for the limits. These were hardcoded to +/-1.571 for a
    # while, so the JOINTS table (and therefore every actuator ctrlrange) carried
    # the measured mechanism travel while the joints themselves let the policy
    # swing 90 degrees into a bracket. check_joints() catches that now.
    rng = {n.split("_", 1)[1]: r for n, _, r, _ in JOINTS if n.startswith("left_")}
    a('      <body name="%s_hip" pos="%s">\n' % (side, m(0, sign * HIP_Y, -TRUNK[2] / 2)))
    a('        <joint name="%s_hip_roll" axis="1 0 0" range="%.3f %.3f"/>\n'
      % (side, *rng["hip_roll"]))
    # The hip_pitch servo rides on the roll link, at the pitch axis.
    a(COS.printed_geom("%s_hip" % side))
    a(servo_geom("%s_hip_pitch_servo" % side, "MG90S", (-6, 0, -HIP_ROLL_TO_PITCH)))
    a(link_geom("%s_hip_bracket" % side, (14, 20, HIP_ROLL_TO_PITCH),
                (0, 0, -HIP_ROLL_TO_PITCH / 2), M_HIP_YOKE))

    a('        <body name="%s_thigh" pos="%s">\n' % (side, m(0, 0, -HIP_ROLL_TO_PITCH)))
    a('          <joint name="%s_hip_pitch" axis="0 1 0" range="%.3f %.3f"/>\n'
      % (side, *rng["hip_pitch"]))
    a(COS.printed_geom("%s_thigh" % side))
    a(servo_geom("%s_knee_servo" % side, "MG92B", (-6, 0, -THIGH)))
    a(link_geom("%s_thigh_link" % side, (12, 16, THIGH), (0, 0, -THIGH / 2), M_THIGH))

    a('          <body name="%s_shin" pos="%s">\n' % (side, m(0, 0, -THIGH)))
    a('            <joint name="%s_knee" axis="0 1 0" range="%.3f %.3f"/>\n'
      % (side, *rng["knee"]))
    a(COS.printed_geom("%s_shin" % side))
    a(servo_geom("%s_ankle_servo" % side, "MG90S", (-6, 0, -SHIN)))
    a(link_geom("%s_shin_link" % side, (10, 14, SHIN), (0, 0, -SHIN / 2), M_SHIN))

    a('            <body name="%s_foot" pos="%s">\n' % (side, m(0, 0, -SHIN)))
    a('              <joint name="%s_ankle" axis="0 1 0" range="%.3f %.3f"/>\n'
      % (side, *rng["ankle"]))
    a(COS.printed_geom("%s_foot" % side))
    a(link_geom("%s_ankle_bracket" % side, (12, 16, ANKLE_TO_SOLE),
                (0, 0, -ANKLE_TO_SOLE / 2), M_FOOT_MOUNT))
    a('              <geom name="%s_sole" type="box" size="%s" pos="%s" mass="%.5f" '
      'class="collision" rgba="0.95 0.55 0.10 1"/>\n'
      % (side, half(FOOT), m(FOOT_X, 0, -ANKLE_TO_SOLE - FOOT[2] / 2), M_SOLE))
    a(COS.cluster_geoms("sole_" + side,
                        (FOOT_X, 0, -ANKLE_TO_SOLE - FOOT[2] / 2)))
    a('              <site name="%s_foot" group="3" pos="%s"/>\n'
      % (side, m(FOOT_X, 0, -ANKLE_TO_SOLE - FOOT[2])))
    a('            </body>\n')
    a('          </body>\n')
    a('        </body>\n')
    a('      </body>\n')
    return "".join(x), roll0


def build_robot() -> str:
    x = []
    a = x.append
    a('<mujoco model="nanoduck">\n')
    # meshdir points at the upstream shells, so the repo keeps exactly one copy
    # of those files and sim/ does not duplicate 26 MB of STL.
    a('  <compiler angle="radian" autolimits="true" '
      'meshdir="../cad/microduck_src"/>\n')
    a('  <option timestep="0.005" iterations="10" ls_iterations="10"/>\n\n')
    a('  <default>\n')
    a('    <!-- Only the soles collide, as in MicroDuck robot_walk.xml: falling is\n')
    a('         cheap during velocity training and the contacts cost solver time. -->\n')
    # Group 3, not 2: these boxes carry the mass and inertia but they stand in
    # for the shells, and at the same size they hide them. A renderer showing
    # group 2 gets the duck; showing group 3 gets the mass model.
    a('    <default class="viz">\n')
    a('      <geom contype="0" conaffinity="0" group="3"/>\n')
    a('    </default>\n')
    a('    <!-- The cosmetic shells: MicroDuck\'s own geometry, visual only.\n')
    a('         Group 2, so a renderer can show the skin and hide the boxes. -->\n')
    a('    <default class="skin">\n')
    # mass="0" is essential: MuJoCo would otherwise infer mass from each mesh's
    # volume and add it on top of the boxes that already carry it. Leaving it
    # out took the robot from 241 g to 398 g without a word of complaint.
    a('      <geom type="mesh" mass="0" contype="0" conaffinity="0" group="2" '
      'rgba="0.96 0.94 0.88 1"/>\n')
    a('    </default>\n')
    a('    <default class="collision">\n')
    a('      <geom contype="1" conaffinity="1" group="3" condim="3" friction="1.0 0.005 0.0001"/>\n')
    a('    </default>\n')
    a('    <!-- Position gains are the MG90S/MG92B closed-loop stiffness. They are\n')
    a('         overwritten anyway when sim/mg90s.py ServoBank.install() takes over,\n')
    a('         but they make the bare model behave sensibly on its own. -->\n')
    a('    <joint damping="0.005" frictionloss="0.012" armature="0.003"/>\n')
    a('  </default>\n\n')

    a('  <asset>\n')
    a(COS.mesh_assets())
    a(COS.printed_assets())
    a('  </asset>\n\n')

    a('  <worldbody>\n')
    a('    <body name="trunk_base" pos="0 0 %.4f">\n' % (trunk_z() * MM))
    a('      <freejoint name="root"/>\n')
    a('      <site name="imu" group="3" pos="0 0 0"/>\n')
    # Trunk contents. Battery low and central; PCB above it.
    a(link_geom("trunk_shell", TRUNK, (0, 0, 0),
                M_CHASSIS + M_TRUNK_SHELL + M_WIRING, "0.95 0.93 0.86 1"))
    a('      <geom name="battery" type="box" size="%s" pos="%s" mass="%.5f" class="viz" '
      'rgba="0.2 0.3 0.6 1"/>\n' % (half((45, 20, 11)), m(0, 0, -8), M_BATTERY))
    a('      <geom name="pcb" type="box" size="%s" pos="%s" mass="%.5f" class="viz" '
      'rgba="0.1 0.4 0.2 1"/>\n' % (half((40, 30, 5)), m(0, 0, 6), M_PCB))
    a(COS.cluster_geoms("trunk", (0.0, 0.0, 0.0)))
    # The hip_roll servos are bolted into the trunk and drive the hip links.
    a(servo_geom("left_hip_roll_servo", "MG90S", (0, HIP_Y, -TRUNK[2] / 2 + 6)))
    a(servo_geom("right_hip_roll_servo", "MG90S", (0, -HIP_Y, -TRUNK[2] / 2 + 6)))
    a(servo_geom("neck_pitch_servo", "micro", (NECK_X, 0, TRUNK[2] / 2 - 5)))
    a('\n')

    left, _ = leg("left", +1)
    right, _ = leg("right", -1)
    a(left)

    # Head
    a('      <body name="neck" pos="%s">\n' % m(NECK_X, 0, TRUNK[2] / 2 - NECK_SINK))
    a('        <joint name="neck_pitch" axis="0 1 0" range="-1.571 1.047"/>\n')
    a(COS.printed_geom("neck"))
    a(servo_geom("head_yaw_servo", "MG90S", (0, 0, NECK_LEN)))
    a(link_geom("neck_link", (10, 12, NECK_LEN), (0, 0, NECK_LEN / 2), M_NECK_LINK))
    a('        <body name="head" pos="%s">\n' % m(0, 0, NECK_LEN))
    a('          <joint name="head_yaw" axis="0 0 1" range="-2.967 2.967"/>\n')
    a(link_geom("head_shell", HEAD, (HEAD_X, 0, HEAD_Z), M_HEAD, "0.95 0.93 0.86 1"))
    a(COS.cluster_geoms("head", (HEAD_X, 0.0, HEAD_Z)))
    # Sensor mounting points, matching MicroDuck's own set so its tooling finds
    # the names it expects. Nothing in the walking observation reads these --
    # that is base_ang_vel and gravity off the trunk IMU -- but the head shell
    # is MicroDuck's and has the holes, so the model should say where they are.
    a('          <site name="head_camera" group="3" pos="%s"/>\n' % m(16, 0, HEAD_Z + 4))
    a('          <site name="tof" group="3" pos="%s"/>\n' % m(16, 9, HEAD_Z + 4))
    a('          <site name="head_imu" group="3" pos="%s"/>\n' % m(0, 0, HEAD_Z))
    a('          <site name="mouth_tip" group="3" pos="%s"/>\n' % m(30, 0, HEAD_Z - 5))
    a('        </body>\n')
    a('      </body>\n')

    a(right)
    a('    </body>\n')
    a('  </worldbody>\n\n')

    # Actuators, in JOINTS order -> this defines the action vector.
    a('  <actuator>\n')
    for name, kind, (lo, hi), _ in JOINTS:
        s = SERVO[kind]
        a('    <position name="%s" joint="%s" kp="%.3f" kv="0" '
          'forcerange="%.3f %.3f" ctrlrange="%.3f %.3f"/>\n'
          % (name, name, s["kp"], -s["tau"], s["tau"], lo, hi))
    a('  </actuator>\n\n')

    # Sensor names match MicroDuck's so scripts/infer_policy.py works unchanged.
    a('  <sensor>\n')
    a('    <gyro name="imu_ang_vel" site="imu"/>\n')
    a('    <accelerometer name="imu_accel" site="imu"/>\n')
    a('    <velocimeter name="imu_lin_vel" site="imu"/>\n')
    a('    <framequat name="orientation" objtype="site" objname="imu"/>\n')
    a('  </sensor>\n')
    a('</mujoco>\n')
    return "".join(x)


def trunk_z() -> float:
    """Height of the trunk centre above the ground in the home pose [mm]."""
    import math
    drop = THIGH * math.cos(HIP_PITCH_0) + SHIN * math.cos(HIP_PITCH_0 + KNEE_0)
    return ANKLE_TO_SOLE + FOOT[2] + drop + HIP_ROLL_TO_PITCH + TRUNK[2] / 2


def _shell_world_bounds(scene_path, names):
    """World-space bounding box [mm] of a set of skin geoms, in the home pose."""
    import mujoco
    import numpy as np
    import trimesh

    m = mujoco.MjModel.from_xml_path(scene_path)
    d = mujoco.MjData(m)
    mujoco.mj_resetDataKeyframe(m, d, 0)
    mujoco.mj_forward(m, d)
    lo = np.full(3, np.inf)
    hi = np.full(3, -np.inf)
    for g in range(m.ngeom):
        n = mujoco.mj_id2name(m, mujoco.mjtObj.mjOBJ_GEOM, g) or ""
        if n not in names:
            continue
        mid = m.geom_dataid[g]
        va, vn = m.mesh_vertadr[mid], m.mesh_vertnum[mid]
        v = m.mesh_vert[va:va + vn].copy()
        v = v @ trimesh.transformations.quaternion_matrix(
            m.geom_quat[g])[:3, :3].T + m.geom_pos[g]
        bi = m.geom_bodyid[g]
        v = v @ d.xmat[bi].reshape(3, 3).T + d.xpos[bi]
        lo = np.minimum(lo, 1000 * v.min(0))
        hi = np.maximum(hi, 1000 * v.max(0))
    return lo, hi


def measure_head_gap(scene_path: str) -> float:
    """mm between the underside of the head shells and the top of the trunk."""
    head = {"skin_" + n for n in COS.GROUPS["head"][1]}
    hlo, _ = _shell_world_bounds(scene_path, head)
    _, thi = _shell_world_bounds(scene_path, {"skin_left_shell", "skin_right_shell"})
    return float(hlo[2] - thi[2])


def check_head_clearance(scene_path: str) -> bool:
    """Does the head sit ON the body rather than inside it?

    This is the check that "the neck looks wrong" turned out to need. The head
    was 10.6 mm inside the trunk, so no neck was visible at all -- and none of
    the existing tests noticed, because every one of them was about the head's
    own orientation or the joint chain, not about two shells trying to occupy
    the same space.
    """
    head = {"skin_" + n for n in COS.GROUPS["head"][1]}
    hlo, hhi = _shell_world_bounds(scene_path, head)
    tlo, thi = _shell_world_bounds(scene_path, {"skin_left_shell", "skin_right_shell"})
    gap = float(hlo[2] - thi[2])
    ok = gap > 0.0
    print()
    print("head / body clearance:")
    print("   head shells  z [%6.1f, %6.1f] mm   x [%6.1f, %6.1f]"
          % (hlo[2], hhi[2], hlo[0], hhi[0]))
    print("   trunk panels z [%6.1f, %6.1f] mm   x [%6.1f, %6.1f]"
          % (tlo[2], thi[2], tlo[0], thi[0]))
    print("   gap          %+6.1f mm   %s" % (gap, "ok" if ok else "HEAD BURIED IN THE BODY"))
    print("   bill reaches %+6.1f mm ahead of the trunk nose" % (hhi[0] - thi[0] * 0 - 34.4))
    return ok
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

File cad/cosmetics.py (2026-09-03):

"""Place MicroDuck's shells on NanoDuck, using MicroDuck's own transforms.

The shells are Onshape exports whose origins and axes are whatever the CAD gave
them.  Guessing at them does not work -- a first attempt centred each mesh and
rotated it 90 degrees, which looked plausible in a render and was wrong.

But the transforms are not actually unknown.  `robot_walk.xml` positions every
one of these meshes inside a body, with an exact pos and quat.  Reusing those
is the difference between alignment and decoration:

    left_shell / right_shell   body trunk_base   quat 0.707107 0 0 0.707107
    top/bottom_head_shell      body jaw_soft     quat 0.5 0.5 0.5 0.5
    face_part, jaw, noenoeil   body jaw_soft     quat 0.5 0.5 0.5 0.5
    sole_left                  body ankle_left   quat 0.5 -0.5 -0.5 -0.5

Within a group the relative positions are already right, so a group only needs
one offset: where the cluster sits on NanoDuck's own body.  That is computed,
not chosen -- each cluster is centred on the primitive geom already carrying its
mass in the MJCF, so the visual shell and the inertia box describe the same
object.
"""

from __future__ import annotations

import os
import re
import struct

import numpy as np
import trimesh

HERE = os.path.dirname(os.path.abspath(__file__))
SRC = os.path.join(HERE, "microduck_src")
MJCF = os.path.join(SRC, "robot_walk.xml")

# group -> (scale, meshes, extra XYZ euler in degrees)
#
# Scale differs per group because the body has to swallow a battery and a PCB
# that do not scale, so it is chubbier than MicroDuck's.
#
# The extra rotation is needed because MicroDuck's body frames are not
# NanoDuck's.  Reusing the upstream pos/quat puts each cluster together
# correctly, but the cluster as a whole still arrives in MicroDuck's axes: the
# head lands with its long (beak) axis along Z instead of X, and a sole with
# its thin axis along Y instead of Z.  One rotation per group fixes that, and
# `python cosmetics.py` prints the resulting extents so it can be checked
# rather than believed.
GROUPS = {
    # head: solved, not chosen. See check_orientation() -- this is the only
    # axis-aligned rotation that puts the top shell above the bottom one, the
    # bill forward, and the long axis fore-aft.
    #
    # It was (180, 90, 0) for a while, which passed a test on the cluster's
    # fore-aft EXTENT and shipped the duck upside down. Extent along X says the
    # long axis is X; it says nothing whatever about a 180 degree flip around
    # it. Up/down and front/back are separate facts and need separate tests.
    # head at the SAME scale as the body, which is the whole point: MicroDuck's
    # head-to-body ratio is 1.52, and any two different scales destroy it. At
    # 0.62 the head measured 1.11 -- 27% too small, which is exactly why the
    # first renders read as "a duck, but wrong". It costs 33 g.
    "head": (0.85, ["bottom_head_shell", "top_head_shell", "face_part", "jaw", "noenoeil"],
             (0.0, 270.0, 0.0)),
    "trunk": (0.85, ["left_shell", "right_shell"], (0.0, 0.0, 0.0)),
    "sole_left": (0.75, ["sole_left"], (90.0, 0.0, 0.0)),
    "sole_right": (0.75, ["sole_right"], (90.0, 0.0, 0.0)),
}


# Per-mesh colour. The shells arrive as separate parts, so this costs nothing
# and it is most of what was left of "it does not look like a MicroDuck": the
# real robot is off-white with an ORANGE bill and brow band and a black eye, and
# a render in one flat cream reads as a generic white robot instead.
COLOUR = {
    "_default":          "0.93 0.92 0.89 1",   # shells
    "jaw":               "0.95 0.45 0.05 1",   # the bill
    "face_part":         "0.95 0.45 0.05 1",   # the band around the brow
    "noenoeil":          "0.09 0.09 0.11 1",   # eye
    "sole_left":         "0.95 0.55 0.10 1",   # webbed feet
    "sole_right":        "0.95 0.55 0.10 1",
}


def extra_matrix(group):
    rx, ry, rz = GROUPS[group][2]
    return trimesh.transformations.euler_matrix(
        np.radians(rx), np.radians(ry), np.radians(rz), "sxyz")


def extra_quat(group):
    q = trimesh.transformations.quaternion_from_matrix(extra_matrix(group))
    return np.asarray(q)


def compose(group, quat):
    """Upstream mesh quat, then the group's extra rotation."""
    q = trimesh.transformations.quaternion_multiply(extra_quat(group), quat)
    return q / np.linalg.norm(q)


def upstream_transforms():
    """mesh name -> (pos [m], quat wxyz) as MicroDuck places it."""
    out = {}
    for line in open(MJCF, encoding="utf-8").read().splitlines():
        g = re.search(r'<geom type="mesh"[^>]*mesh="([^"]+)"', line)
        if not g:
            continue
        p = re.search(r'pos="([^"]*)"', line)
        q = re.search(r'quat="([^"]*)"', line)
        if not p or not q or g.group(1) in out:
            continue
        out[g.group(1)] = (np.array([float(v) for v in p.group(1).split()]),
                           np.array([float(v) for v in q.group(1).split()]))
    return out


def load_stl_mm(name):
    with open(os.path.join(SRC, name + ".stl"), "rb") as f:
        d = f.read()
    n = struct.unpack("<I", d[80:84])[0]
    a = np.frombuffer(d[84:84 + 50 * n], dtype=np.uint8).reshape(n, 50)
    v = a[:, 12:48].copy().view(np.float32).reshape(n, 3, 3) * 1000.0
    return trimesh.Trimesh(vertices=v.reshape(-1, 3),
                           faces=np.arange(n * 3).reshape(n, 3), process=True)


def quat_matrix(q):
    w, x, y, z = q
    return trimesh.transformations.quaternion_matrix([w, x, y, z])


def cluster_bounds(group):
    """Bounds [mm] of a posed, scaled cluster, in NanoDuck's body axes."""
    scale, names, _ = GROUPS[group]
    tf = upstream_transforms()
    E = extra_matrix(group)
    lo = np.full(3, np.inf)
    hi = np.full(3, -np.inf)
    for name in names:
        if name not in tf:
            continue
        m = load_stl_mm(name)
        m.apply_scale(scale)
        pos, quat = tf[name]
        m.apply_transform(quat_matrix(quat))
        m.apply_translation(pos * 1000.0 * scale)
        m.apply_transform(E)
        lo = np.minimum(lo, m.bounds[0])
        hi = np.maximum(hi, m.bounds[1])
    return lo, hi
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

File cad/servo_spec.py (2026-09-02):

"""MG90S / MG92B mechanical interface, in one place.

Every printed part in `parts.py` is cut from these numbers, so if your servos
measure differently you change this file and reprint -- nothing else.

VERIFY THESE WITH CALIPERS BEFORE PRINTING A FULL SET.
These are the commonly published Tower Pro figures, and MG90S clones vary by
several tenths of a millimetre in exactly the dimensions that matter (case
width, ear thickness, hole spacing).  A pocket 0.3 mm too small will not close;
0.5 mm too large and the servo rocks in its mount, which shows up as backlash
the policy was never trained for.

`parts.py --coupon` prints a 12 g test piece carrying one pocket, one pair of
ear holes and one bearing seat.  Print that first.  It takes ten minutes and
saves a whole set.

Coordinates for a servo, as used throughout:
    +X  along the case length (the 22.8 mm dimension)
    +Y  across the case width (the 12.2 mm dimension, the thin one)
    +Z  up the case height, output shaft pointing +Z
    origin at the centre of the OUTPUT SHAFT, on the bottom face of the case
"""

from __future__ import annotations

from dataclasses import dataclass


@dataclass(frozen=True)
class ServoSpec:
    name: str
    case_l: float          # case length, without the mounting ears
    case_w: float          # case width -- the thin axis
    case_h: float          # bottom of case to top of case, no output boss
    ear_span: float        # overall length across both mounting ears
    ear_t: float           # ear thickness
    ear_z: float           # height of the ear underside above the case bottom
    hole_pitch: float      # centre-to-centre of the two mounting holes
    hole_d: float          # mounting hole diameter (M2 clearance)
    shaft_from_end: float  # output shaft axis, measured from the shaft-side end
    boss_d: float          # diameter of the round boss the shaft sits on
    boss_h: float          # boss height above the case top
    shaft_d: float         # spline outside diameter
    horn_screw_d: float    # the self-tapper that holds a horn on
    mass: float            # kg
    cable_w: float         # cable exit width, for the relief slot

    @property
    def shaft_to_far_end(self) -> float:
        return self.case_l - self.shaft_from_end

    @property
    def total_h(self) -> float:
        return self.case_h + self.boss_h


# Tower Pro MG90S.
MG90S = ServoSpec(
    name="MG90S",
    case_l=22.8, case_w=12.2, case_h=22.7,
    ear_span=32.2, ear_t=2.5, ear_z=16.0,
    hole_pitch=28.0, hole_d=2.2,
    shaft_from_end=5.9,
    boss_d=7.4, boss_h=4.0, shaft_d=4.8,
    horn_screw_d=1.8,
    mass=0.0134,
    cable_w=6.0,
)

# MG92B: same envelope, marginally taller. Knees only.
MG92B = ServoSpec(
    name="MG92B",
    case_l=22.8, case_w=12.2, case_h=24.7,
    ear_span=32.2, ear_t=2.5, ear_z=16.0,
    hole_pitch=28.0, hole_d=2.2,
    shaft_from_end=5.9,
    boss_d=7.4, boss_h=4.0, shaft_d=4.8,
    horn_screw_d=1.8,
    mass=0.0138,
    cable_w=6.0,
)

# Generic 3.7 g micro servo (neck pitch, head yaw).
MICRO = ServoSpec(
    name="micro3.7g",
    case_l=20.0, case_w=8.4, case_h=17.0,
    ear_span=27.5, ear_t=2.0, ear_z=11.5,
    hole_pitch=23.5, hole_d=2.2,
    shaft_from_end=5.0,
    boss_d=5.4, boss_h=3.0, shaft_d=3.8,
    horn_screw_d=1.5,
    mass=0.0037,
    cable_w=4.5,
)

SERVOS = {"MG90S": MG90S, "MG92B": MG92B, "micro": MICRO}

# --- Print and hardware settings ---------------------------------------------
# Clearances are for a well-tuned 0.4 mm nozzle on PETG.  PETG swells more than
# PLA, so these are on the generous side; drop CLEAR to 0.15 for PLA.
CLEAR = 0.25            # added to every pocket that has to receive a part
WALL = 1.6              # structural wall thickness: 4 perimeters at 0.4 mm
FLOOR = 1.2             # thickness of a load-bearing floor: 3 layers at 0.4

M2_CLEAR = 2.2          # through-hole for an M2 screw
M2_TAP = 1.7            # hole to drive an M2 self-tapper straight into plastic
M2_HEAD_D = 4.0         # M2 cap-head diameter, for counterbores
M2_NUT_AF = 4.0         # M2 nut across-flats
M2_NUT_T = 1.6          # M2 nut thickness

# MR63ZZ, the idler bearing that sits opposite the horn on every joint.  The
# MG90S output shaft is single-sided, so without this the joint is a cantilever
# on a 4.8 mm plastic spline and the leg wags visibly under load.
BEARING_OD = 6.0
BEARING_ID = 3.0
BEARING_T = 2.5
PIVOT_D = 3.0           # the 3 mm shoulder that runs in the bearing
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

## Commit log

2026-09-02 NanoDuck: sizing analysis, MG90S actuator model, CAD and BOM
    A MicroDuck scaled down onto MG90S hobby servos. Every number here comes
    from measurement, not catalogue arithmetic: joint torque and speed are
    recorded from the shipping walking policy running in CPU MuJoCo, and the
    mass breakdown is measured off the CAD meshes.
    analysis/ Torque-speed sizing against the real demand (5348 paired samples).
    Calibrated by the XL330 control case reproducing "the real knee
    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
    [ankle_l_v1.stl, ankle_left.stl, ankle_r_v1.stl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]
2026-09-02 NanoDuck v2: clean-sheet design around the MG90S
    v1 tried to shrink MicroDuck and hit a wall: torque allowed s <= 0.56 while
    geometry needed s >= 0.95, because an MG90S is not a small servo, it is a
    thin one -- 95% of an XL330's length. Freed from copying MicroDuck, the
    design closes.
    Reframed the sizing. A single scale factor s forces one number onto
    everything and hides that the joints only care about two things, which can
    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
    [ankle_l_v1.stl, ankle_left.stl, ankle_r_v1.stl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]
2026-09-02 NanoDuck: build the model -- 10 DOF, 196 g, 162 mm, and it stands
    cad/build_nanoduck.py generates sim/nanoduck.xml and sim/scene_nanoduck.xml
    from the design parameters, so a change to leg length or a servo mass moves
    the model, the keyframe, the actuator limits and the home pose together.
    Every body frame is axis-aligned in the home pose, which makes joint axes
    literally "1 0 0" / "0 1 0" / "0 0 1" -- readable, unlike an Onshape export.
    sim/stand_test.py holds the home pose under gravity. All three servo
    configurations stand with 0.2 mm sag, 0.00 mm rms and zero saturation, so
    the deadband does not set up a limit cycle. Standing is the easy half and
    the test says so.
    Three things the buil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
    [bom.csv]
2026-09-02 Add licensing before making the repository public
    Mirrors microduck_rl's own two-part split, because part of this repo is
    derived from it: Apache 2.0 for the code, CC BY-NC-SA 4.0 for the meshes in
    cad/microduck_src/ and for analysis/microduck_demand.npz, which was measured
    on that model. Non-commercial and share-alike carry over.
    NOTICE.md records why those upstream files are vendored -- check_servo_fit.py
    measures the XL330 envelope out of xl330.stl and the link lengths out of
    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
2026-09-02 Printable parts: 20 STLs, generated and checked before export
    cad/parts.py generates the structure by CSG against servo_spec.py, and reuses
    MicroDuck's own shells for the cosmetics -- head, bill, body panels, eyes and
    webbed feet are the real geometry, scaled, not an imitation.
    Nothing is exported until it passes three checks, and all three caught real
    defects that a render would not have:
    * kinematic length -- a 3 mm probe cylinder swept along each link locates the
    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
    [assembly.stl, cosmetic_bottom_head_shell.stl, cosmetic_face_part.stl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]
2026-09-02 Show the real geometry in the sim, not boxes
    The MJCF render in the README was primitives, which is what the model was.
    Now the model carries visual meshes: MicroDuck's own head, body and sole
    shells, plus the printed leg brackets from cad/print. The boxes still carry
    the mass and inertia, moved to group 3, so a renderer picks the duck or the
    mass model by geom group.
    The shells are placed from MicroDuck's own transforms rather than guessed.
    robot_walk.xml positions every one of these meshes with an exact pos and
    quat, so within a group the relative geometry is already correct and only a
    per-group rotation and offset remain -- and the offset is computed by
    centring each cluster on the primi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
    [build_nanoduck.py, cosmetics.py]
2026-09-02 Fix the upside-down head, and the joint limits that never reached the joints
    Two real defects, both found by replacing a claim with a test.
    The head was upside down. It was placed with a (180, 90, 0) rotation and
    "verified" by measuring the cluster's fore-aft extent: 76.1 mm, which is
    MicroDuck's 123 mm head at 0.62, therefore aligned. That reasoning is wrong.
    An extent along X proves the long axis is X and is perfectly happy with the
    head flipped 180 degrees about that same axis. Up/down and front/back are
    separate facts and need separate tests.
    cosmetics.check_orientation() now tests them separately, as signed distances
    between parts whose relative position is not in doubt: the top shell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
    [build_nanoduck.py, cosmetics.py]
2026-09-03 Audit the head: proportion, drive, and sensors
    The head looked wrong because it was wrong, and measuring it turned up a
    second defect underneath.
    Proportion. MicroDuck's head-to-body ratio is 1.52. NanoDuck's was 1.11 --
    27% small -- because the head was scaled 0.62 and the body 0.85, and any two
    different scales destroy the ratio whatever the numbers are. The head is now
    at the body's 0.85 and the ratio is exact. It costs 43 g and takes the worst
    joint from 76% to 90%, which is over MicroDuck's own knee and is stated as
    such: the cheapest gram on this robot is head scale.
    Drive. design_point.py transferred head-joint demand by robot mass and LEG
    length. A neck servo carries the head, not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
    [bom.csv, cosmetic_bottom_head_shell.stl, cosmetic_face_part.stl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]
2026-09-03 Fix the hip: its two joint axes were parallel and had to be perpendicular
    The hip bracket could not have been assembled.
    The MJCF has hip_roll on [1 0 0] and hip_pitch on [0 1 0] -- 90 degrees apart,
    as a roll-into-pitch hip must be. parts.py built every link with both ends on
    the part frame's Y, so the printed hip_yoke held its two joints PARALLEL. The
    neck was wrong the same way (neck_pitch [0 1 0] -> head_yaw [0 0 1]). The two
    leg links in the middle of the chain, thigh and shin, are 0 degrees at both
    ends and were always right.
    Nothing in the pipeline noticed. The meshes were watertight and single-bodied,
    the axis spacing measured to 0.00 mm, the travel sweep passed, and the MJCF
    happi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
    [hip_yoke_a_L.stl, hip_yoke_a_R.stl, hip_yoke_b_L.stl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]
2026-09-03 Fix the neck: part inverted, head buried, and no colour
    "The neck looks wrong" was three separate defects.
    The printed neck part was upside down. parts.link() builds every part with
    its driving joint at -Z, which is correct for all six leg parts and backwards
    for the one link that runs UP. The part spanned z -44 to +5 while the head sat
    at +20, so it pointed down into the trunk. Caught by asking whether each
    parent's part actually reaches the joint it drives -- the six leg parts pass,
    the neck did not.
    The head was 10.6 mm inside the body, which is what "no visible neck" really
    was: there was a neck, the head was just swallowing it. NECK_SINK 8 mm and
    HEAD_Z 4 mm were reasonable for a 37 m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
    [build_nanoduck.py, cosmetics.py]
